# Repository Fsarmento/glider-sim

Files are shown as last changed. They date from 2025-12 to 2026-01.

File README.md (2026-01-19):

# glider-sim

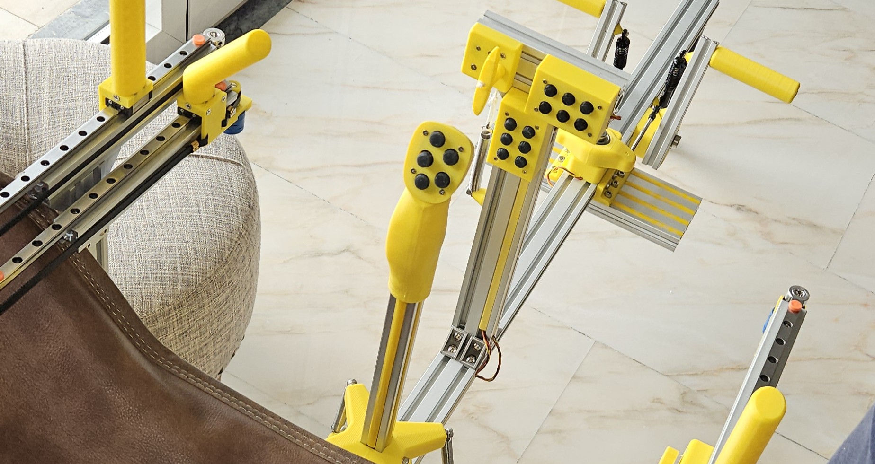
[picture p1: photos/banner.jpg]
Glider Sim


A glider flight simulation cockpit project. Includes 3D printable STL parts, bill of materials, and controller code.
This project was designed to be used with the **Condor 3** glider flight simulator.

---

If you enjoy this project and want to say thanks, you can **buy me a beer** via [GitHub Sponsors](https://github.com/sponsors/Fsarmento). 🍺

---

> [!NOTE]
> If you have any questions about this project, please use the [Discussions](https://github.com/Fsarmento/glider-sim/discussions) section. I'll try to answer them.

## Table of Contents

- [Introduction](#introduction)
- [Bill of Materials (BOM)](#bill-of-materials-bom)
  - [Frame](#frame)
  - [Joystick base](#joystick-base)
  - [Joystick controller](#joystick-controller)
  - [Rudder pedals](#rudder-pedals)
  - [Sliders](#sliders-up-to-3-sets-airbreaks-flaps-and-gear)
  - [Controller box](#controller-box)
  - [Trim lever](#trim-lever)
  - [Tow release](#tow-release)
  - [6-buttons box](#6-buttons-box-up-to-2-sets)
  - [Chair holder](#chair-holder)
  - [Wiring & connectors](#wiring--connectors)
- [Electronics overview](#electronics-overview)
  - [Main controller](#main-controller-glider_sim_main)
  - [Stick buttons controller](#stick-buttons-controller-glider_sim_stick_buttons)
  - [6-button box controller](#6button-box-controller-glider_sim_6_buttons)
- [Connections and Setup](#connections-and-setup)
- [Credits](#credits)
- [Photos](#photos)

---

## Introduction

This project uses aluminum profiles for the structure, 3D-printed parts, three PCBs to simplify electronic assembly, and accessories that can be easily purchased online from AliExpress or Banggood.
To assemble this cockpit, you will need a 3D printer and a soldering iron for electronics.

All 3D drawings are located in the `/stl` folder, organized into subfolders to make it easier to identify which module they belong to. I used PLA with 20% infill for all parts.

The links in the BOM list often point to sets, such as screw kits, where a single set contains the materials needed for multiple BOM lines.

For position sensing, the rudder pedals and joystick gimbal use linear Hall effect sensors (SS496A1), the sliders use 10-turn 10kΩ potentiometers, the trim lever uses a standard B10K potentiometer, and the tow release uses an end-switch commonly found in 3D printers.

The main controller uses an Arduino Pro Micro and is detected by the PC as a standard joystick. The stick buttons and each 6-button box use ESP32-C3 Supermini controllers. To simplify assembly without taking up much space, I designed 3 PCBs and provide the GERBER files in ZIP format in the `/PCB` folder. Nowadays, it is so easy and affordable to have PCBs manufactured that it makes sense to have boards custom-sized to your needs. To have the boards produced, simply go to the [JLCPCB](https://cart.jlcpcb.com/quote) website and upload the zip file. You do not need to change any of the default options on the site. With the cheapest shipping method, the production and shipping of each PCB costs around €7. In the case of the stick buttons, as space is very limited, I could only fit everything using SMD (surface-mount) buttons, which are harder to solder. For this reason, I suggest using the PCBA service to assemble the front of the PCB already with the buttons supplied by JLCPCB. To do this, at the bottom of the JLCPCB PCB configuration page, simply enable the "PCB Assembly" option and on the next page upload the BOM and CPL files provided inside the `/PCB` folder.

The code to upload to each controller is located inside the `/scripts` folder. You can use the Arduino IDE to upload the code to each controller.

I hope you enjoy assembling the cockpit and "flying" as much as I did!

> [!TIP]
> To understand how the Hall sensors work and how they should be installed, watch this video by Tim Station: [https://youtu.be/XcKmBWGFUn8?t=36&si=NRGCK4p2wdxqQ4Bu](https://youtu.be/XcKmBWGFUn8?t=36&si=NRGCK4p2wdxqQ4Bu)

## Bill of Materials (BOM)

> [!IMPORTANT]
> The AliExpress links do not have the correct product options pre-selected. Please make sure to select the correct options according to the item description.

### Frame

| Quantity | Type | Size | Length | Description | Shop |
|---|---|---|---|---|---|
| 1 | Aluminium Profile | 4040 | 900 | main frame | |
| 1 | Aluminium Profile | 4040 | 600 | side frame | |
| 3 | Aluminium Profile | 2040 | 300 | vertial arms | |
| 1 | Aluminium Profile | 2040 | 120 | front panel | |
| 3 | Aluminium Profile | 2020 | 200 | sliders | |
| 1 | Aluminium Profile | 2020 | 300 | joystick | |
| 2 | Aluminium Profile | 2020 | 150 | pedals | |
| 1 | Aluminium Profile | 2080 | 300 | feet rest | |
| 14 | Profile T connectors | 2020 |  | Profile Connector Corner Bracket set | [Link](https://s.click.aliexpress.com/e/_c4St6Xq9) |
| 2 | Profile 90 deg connector | 2020-2 L40 |  | L connector 2020-2 L40 (sliders base) | [Link](https://s.click.aliexpress.com/e/_c4KEbXQH) |
| 4 | Profile 90 deg connector | 2020-2 L20 |  | L connector 2020-2 L20 (sliders base) | [Link](https://s.click.aliexpress.com/e/_c4KEbXQH) |
| 1 | Profile 90 deg connector | 2040B-6 |  | L connector 2040B-6 (secondary slider) | [Link](https://s.click.aliexpress.com/e/_c4KEbXQH) |
| 3 | Telescopic Feet |  | 16.5CM-28.5CM | Telescopic Feet 16.5CM-28.5CM | [Link](https://s.click.aliexpress.com/e/_c4MEUecl) |
| 1 | Profile Slot Cover | 6mm (20 series) |  | Plastic Profile Slot Cover 20 Series | [Link](https://s.click.aliexpress.com/e/_c3PiaaX3) |

### Joystick base

| Quantity | Type | Size | Length | Description | Shop |
|---|---|---|---|---|---|
| 4 | Bearings | 10x26x8mm |  | Bearings 10x26x8mm (Inside diameter x Outside diameter x Width) | [Link](https://www.aliexpress.com/item/1005007668446060.html) |
| 2 | Shoulder Bolts | D10M8 | 20 | M8x20 Shoulder Bolts (10mm shoulder, 8mm thread) | [Link](https://s.click.aliexpress.com/e/_c3ETZkxx) |
| 2 | Shoulder Bolts | D10M8 | 10 | M8x10 Shoulder Bolts (10mm shoulder, 8mm thread) | [Link](https://s.click.aliexpress.com/e/_c3ETZkxx) |
| 8 | Bolts (Option A) | M5 | 10 | M5x10 Bolts DIN912 to fix springs | [Link](https://s.click.aliexpress.com/e/_c3y9Zvm3) |
| 5 | Bolts | M5 | 14 | M5x14 Bolts DIN912 | [Link](https://s.click.aliexpress.com/e/_c3y9Zvm3) |
| 10 | Bolts | M5 | 20 | M5x20 Bolts DIN912 | [Link](https://s.click.aliexpress.com/e/_c3y9Zvm3) |
| 15 | T-slot Nuts | M5 |  | M5 T-slot Nuts | [Link](https://s.click.aliexpress.com/e/_c3ZBusUH) |
| 2 | Magnets | 8x8x8 |  | 8mm cube magnets | [Link](https://s.click.aliexpress.com/e/_c4EhHqoz) |
| 2 | Hall Effect Sensor |  |  | Hall Effect Sensor SS496A1 | [Link](https://s.click.aliexpress.com/e/_c4PvMVrB) |
| 4 | Option A: Springs |  | 75 | 75x10x1.25mm Springs (Length x Outside Diameter x Wire Diameter) | [Link](https://s.click.aliexpress.com/e/_c2zo177f) |
| 4 | Option B: Oil shock absorber |  | 110 | oil shock absorber 110mm | [Link](https://s.click.aliexpress.com/e/_c3EF2605) |
| 4 | Option B: M3-M5 Adapter | M3-M5 | 10 | M3-M5  10mm Thread Adapter Screw Nuts | [Link](https://pt.aliexpress.com/item/1005007436046737.html) |

### Joystick controller

| Quantity | Type | Size | Length | Description | Shop |
|---|---|---|---|---|---|
| 4 | M2-M4 Adapter | M2-M4 | 8 | M2-M4  8mm Thread Adapter Screw Nuts | [Link](https://pt.aliexpress.com/item/1005007436046737.html) |
| 4 | Flat Bolts | M2 | 10 | M2x10 Flat Countersunk Head Bolt  | [Link](https://s.click.aliexpress.com/e/_c368gRLJ) |
| 1 | Controller ESP32-C3 |  |  | ESP32-C3 Supermini | [Link](https://s.click.aliexpress.com/e/_c2RvZ7EN) |
| 1 | Liquid Rubber |  |  | Silicon Liquid Rubber (buttons) | [Link](https://s.click.aliexpress.com/e/_c4Xd5cIh) |
| 1 | Black Pigment |  |  | Solid Color Black Pigment (buttons color) | [Link](https://pt.aliexpress.com/item/1005005830256537.html) |
| 1 | Option A: PCB stick-buttons |  |  | PCB stick-buttons | |
| 1 | Option A: Connector |  |  | JST-XH 2.54 connectors | [Link](https://s.click.aliexpress.com/e/_c3qvb13l) |
| 4 | Option B: Push Button Switch | 6x6x4.1 |  | (If  using 3D printed part instead of PCB) Push Button Switch  4x4x4.1 DIP (4x4x4.3 is also ok) | [Link](https://s.click.aliexpress.com/e/_c4dK0HMX) |
| 1 | Option B: 5-way Switch | 10x10x10 |  | (If  using 3D printed part instead of PCB) 5-way tactile switch 10x10x10 DIP | [Link](https://s.click.aliexpress.com/e/_c458W5dT) |

### Rudder pedals:

| Quantity | Type | Size | Length | Description | Shop |
|---|---|---|---|---|---|
| 3 | Shoulder Bolts | D10M8 | 30 | M8x30 Shoulder Bolts | [Link](https://s.click.aliexpress.com/e/_c3ETZkxx) |
| 6 | Bearings | 10x26x8mm |  | Bearings 10x26x8mm (Inside diameter x Outside diameter x Width) | [Link](https://www.aliexpress.com/item/1005007668446060.html) |
| 14 | Bolts | M5 | 10 | M5x10mm Bolts DIN912 (Feet Rest) | [Link](https://s.click.aliexpress.com/e/_c3y9Zvm3) |
| 4 | Bolts | M5 | 14 | M5x14mm Bolts DIN912 (Option A - Springs) | [Link](https://s.click.aliexpress.com/e/_c3y9Zvm3) |
| 16 | Bolts | M5 | 20 | M5x20mm Bolts DIN912 | [Link](https://s.click.aliexpress.com/e/_c3y9Zvm3) |
| 32 | T-slot Nuts | M5 |  | M5 T-slot Nuts | [Link](https://s.click.aliexpress.com/e/_c3ZBusUH) |
| 6 | T-slot Nuts | M3 |  | M3 T-slot Nuts | [Link](https://s.click.aliexpress.com/e/_c3ZBusUH) |
| 2 | Bolts | M5 | 100 | M5x100mm Bolts DIN912 | [Link](https://s.click.aliexpress.com/e/_c3y9Zvm3) |
| 2 | Link Rods | M3 | 110 | Stainless steel link rods with rod ends 110mm | [Link](https://s.click.aliexpress.com/e/_c3kGKZzb) |
| 2 | M3-M5 Adapter | M3-M5 | 10 | M3-M5  10mm Thread Adapter Screw Nuts (Link rod) | [Link](https://pt.aliexpress.com/item/1005007436046737.html) |
| 6 | Bolts | M3 | 20 | M3x18mm Bolts (link spacer/shock absorber) | [Link](https://s.click.aliexpress.com/e/_c3PQiYDP) |
| 2 | Bolts | M3 | 16 | M3x16mm Bolts (Shock absorber) | [Link](https://s.click.aliexpress.com/e/_c3PQiYDP) |
| 2 | Magnets | 8x8x8 |  | 8mm cube magnets | [Link](https://s.click.aliexpress.com/e/_c4EhHqoz) |
| 1 | Hall Effect Sensor |  |  | Hall Effect Sensor SS496A1 | [Link](https://s.click.aliexpress.com/e/_c4PvMVrB) |
| 2 | Option A: Springs |  | 75 | 75x10x1.25mm Springs (Length x Outside Diameter x Wire Diameter) | [Link](https://s.click.aliexpress.com/e/_c2zo177f) |
| 2 | Option B: Oil shock absorber |  | 110 | oil shock absorber 110mm | [Link](https://s.click.aliexpress.com/e/_c3B7cY09) |

### Sliders (up to 3 sets: airbreaks, flaps and gear)

| Quantity | Type | Size | Length | Description | Shop |
|---|---|---|---|---|---|
| 1 | Linear Guide Rail | MGN9C | 300 | Linear Guide Rail MGN9C, 300mm | [Link](https://s.click.aliexpress.com/e/_c4Eh7oYL) |
| 1 | Potentiometer | 10k Ohm |  | 10‑turn rotary potentiometer 10k Ohm | [Link](https://s.click.aliexpress.com/e/_c3l51dZt) |
| 1 | GT2 Idler | 20T W6 B5 |  | GT2  Idler 20 Tooth Width 6mm Bore 5mm | [Link](https://pt.aliexpress.com/item/1005003291106065.html) |
| 1 | GT2 belt | 6mm | 2m | GT2-6mm belt 2m (1 for 3 sets) | [Link](https://s.click.aliexpress.com/e/_c3UojoNn) |
| 2 | GT2 Belt Clamp | 6mm |  | GT2 Belt Clamp | [Link](https://s.click.aliexpress.com/e/_c39U7WKh) |
| 2 | Bolts | M5 | 8 | M5x8mm Bolts DIN912 (potentiometer arm) | [Link](https://s.click.aliexpress.com/e/_c3y9Zvm3) |
| 2 | Flat Bolts | M3 | 8 | M3x8 Flat Countersunk Head Bolt  (fix linear guided rail to 2020 profile) | [Link](https://s.click.aliexpress.com/e/_c368gRLJ) |
| 1 | Bolts | M3 | 16 | M3x16  Bolt  (fix GT2 Idler with Pulley Spacer) | [Link](https://s.click.aliexpress.com/e/_c368gRLJ) |
| 2 | Heat Insert Nut | M3 | 5 | Heat Insert Nut M3x5x4 (Inside diameter x length x outside diameter) for handle | [Link](https://s.click.aliexpress.com/e/_c4eRekuz) |
| 2 | Heat Insert Nut | M3 | 4 | Heat Insert Nut M3x4x4 (Inside diameter x length x outside diameter) for handle base | [Link](https://s.click.aliexpress.com/e/_c4eRekuz) |
| 4 | Flat Bolts | M3 | 12 | M3x12 Flat Countersunk Head Bolt  (fix base to linear guided rail carriage) | [Link](https://s.click.aliexpress.com/e/_c368gRLJ) |
| 4 | Flat Bolts | M3 | 8 | M3x8 Flat Countersunk Head Bolt  (fix handle & rubber belt link to base) | [Link](https://s.click.aliexpress.com/e/_c368gRLJ) |
| 2 | T-slot Nuts | M5 |  | M5 T-slot Nuts | [Link](https://s.click.aliexpress.com/e/_c3ZBusUH) |
| 3 | T-slot Nuts | M3 |  | M3 T-slot Nuts | [Link](https://s.click.aliexpress.com/e/_c3ZBusUH) |

### Controller box

| Quantity | Type | Size | Length | Description | Shop |
|---|---|---|---|---|---|
| 1 | Arduino pro micro |  |  | Arduino Pro Micro ATmega32U4 5V/16MHz | [Link](https://s.click.aliexpress.com/e/_c3PIP7hh) |
| 3 | pin headers |  |  | 2.54mm pin headers 3x 1x12 | [Link](https://s.click.aliexpress.com/e/_c3GXfIir) |
| 2 | Flat Bolts | M3 | 8 | M3x8 Flat Countersunk Head Bolt  (fix base to profile) | [Link](https://s.click.aliexpress.com/e/_c368gRLJ) |
| 2 | T-slot Nuts | M3 |  | M3 T-slot Nuts | [Link](https://s.click.aliexpress.com/e/_c3ZBusUH) |
| 3 | Heat Insert Nut | M2 | 3 | Heat Insert Nut M2x3x3.5 (Inside diameter x length x outside diameter) | [Link](https://s.click.aliexpress.com/e/_c4eRekuz) |
| 3 | Bolts | M2 | 5 | M2x5 Bolt | [Link](https://s.click.aliexpress.com/e/_c368gRLJ) |
| 1 | PCB glider-sim |  |  | PCB glider-sim | |

### Trim lever

| Quantity | Type | Size | Length | Description | Shop |
|---|---|---|---|---|---|
| 1 | Potentiometer |  |  | B10k Potentiometer | [Link](https://s.click.aliexpress.com/e/_c3d0xxqx) |
| 2 | Bolts | M5 | 10 | M5x10mm Bolts DIN912 | [Link](https://s.click.aliexpress.com/e/_c3y9Zvm3) |
| 2 | T-slot Nuts | M5 |  | M5 T-slot Nuts | [Link](https://s.click.aliexpress.com/e/_c3ZBusUH) |

### Tow release

| Quantity | Type | Size | Length | Description | Shop |
|---|---|---|---|---|---|
| 1 | End-switch |  |  | End-switch | [Link](https://s.click.aliexpress.com/e/_c3PR1Lm7) |
| 2 | Flat Bolts | M3 | 16 | M3x16 Flat Countersunk Head Bolt  (fix base to profile) | [Link](https://s.click.aliexpress.com/e/_c368gRLJ) |
| 2 | T-slot Nuts | M3 |  | M3 T-slot Nuts | [Link](https://s.click.aliexpress.com/e/_c3ZBusUH) |
| 2 | Flat Bolts | M2 | 10 | M2x10 Flat Countersunk Head Bolt  (fix end-switch) | [Link](https://s.click.aliexpress.com/e/_c368gRLJ) |
| 2 | Nut | M2 |  | M2 nut  (fix end-switch) | [Link](https://s.click.aliexpress.com/e/_c368gRLJ) |
| 2 | Washer | M2 |  | M2 washer  (fix end-switch) | [Link](https://s.click.aliexpress.com/e/_c368gRLJ) |
| 1 | Cord  | 1mm |  | 1mm cord  | [Link](https://s.click.aliexpress.com/e/_c3sErffN) |
| 1 | Spring |  | 75 | 75x10x1.25mm Springs (Length x Outside Diameter x Wire Diameter) | [Link](https://s.click.aliexpress.com/e/_c2zo177f) |
| 1 | Bolts | M5 | 14 | M5x14mm Bolts DIN912 (Spring) | [Link](https://s.click.aliexpress.com/e/_c3y9Zvm3) |
| 1 | T-slot Nuts | M5 |  | M5 T-slot Nuts | [Link](https://s.click.aliexpress.com/e/_c3ZBusUH) |

### 6-buttons box (up to 2 sets)

| Quantity | Type | Size | Length | Description | Shop |
|---|---|---|---|---|---|
| 4 | Heat Insert Nut | M2 | 4 | Heat Insert Nut M2x4x3.5 (Inside diameter x length x outside diameter) | [Link](https://s.click.aliexpress.com/e/_c4eRekuz) |
| 4 | Bolts | M2 | 5 | M2x5 Bolt | [Link](https://s.click.aliexpress.com/e/_c368gRLJ) |
| 2 | Bolts | M5 | 8 | M5x8 Bolt ISO7380 (use bolt from profile T connectors) | [Link](https://s.click.aliexpress.com/e/_c3y9Zvm3) |
| 2 | T-slot Nuts | M5 |  | M5 T-slot Nuts | [Link](https://s.click.aliexpress.com/e/_c3ZBusUH) |
| 1 | Controller ESP32-C3 |  |  | ESP32-C3 Supermini | [Link](https://s.click.aliexpress.com/e/_c2RvZ7EN) |
| 6 | Push Button Switch | 6x6x4.1 |  | Push Button Switch  4x4x4.1 DIP (4x4x4.3 is also ok) | [Link](https://s.click.aliexpress.com/e/_c4dK0HMX) |
| 1 | Option A: Connector |  |  | 2.54mm pin header L 1x3 | [Link](https://s.click.aliexpress.com/e/_c3WdSsM7) |
| 1 | Option B: Connector |  |  | JST-XH 2.54 connectors | [Link](https://s.click.aliexpress.com/e/_c3qvb13l) |
| 1 | Liquid Rubber |  |  | Silicon Liquid Rubber (buttons) | [Link](https://s.click.aliexpress.com/e/_c4Xd5cIh) |
| 1 | Black Pigment |  |  | Solid Color Black Pigment (buttons color) | [Link](https://pt.aliexpress.com/item/1005005830256537.html) |
| 1 | PCB 6-button-box |  |  | PCB 6-button-box | |

### Chair holder

| Quantity | Type | Size | Length | Description | Shop |
|---|---|---|---|---|---|
| 2 | Crab Clamp |  |  | Crab Clamp with 3/8" hole | [Link](https://s.click.aliexpress.com/e/_c2xOmsnF) |
| 2 | Bolts | 3/8" | 2" | UNC hex socket cap screw 3/8-16 Length: 2" | [Link](https://s.click.aliexpress.com/e/_c3Cszrbf) |
| 8 | Bolts | M5 | 14 | M5x14 Bolts | [Link](https://s.click.aliexpress.com/e/_c3y9Zvm3) |
| 8 | T-slot Nuts | M5 |  | M5 T-slot Nuts | [Link](https://s.click.aliexpress.com/e/_c3ZBusUH) |

### Wiring & connectors

| Quantity | Type | Size | Length | Description | Shop |
|---|---|---|---|---|---|
| 2 | Cables | 26AWG | 10m | 26AWG servo extension cable 10m | [Link](https://s.click.aliexpress.com/e/_c3AXPQ6B) |
| 12 | Connectors |  |  | servo JR Male connectors (set of 20) | [Link](https://s.click.aliexpress.com/e/_c2uRVjab) |

## Electronics overview

This project includes three **electronic** modules: the main controller, the stick buttons controller, and the 6‑button box controller.

---

### Main controller (Glider_sim_main)

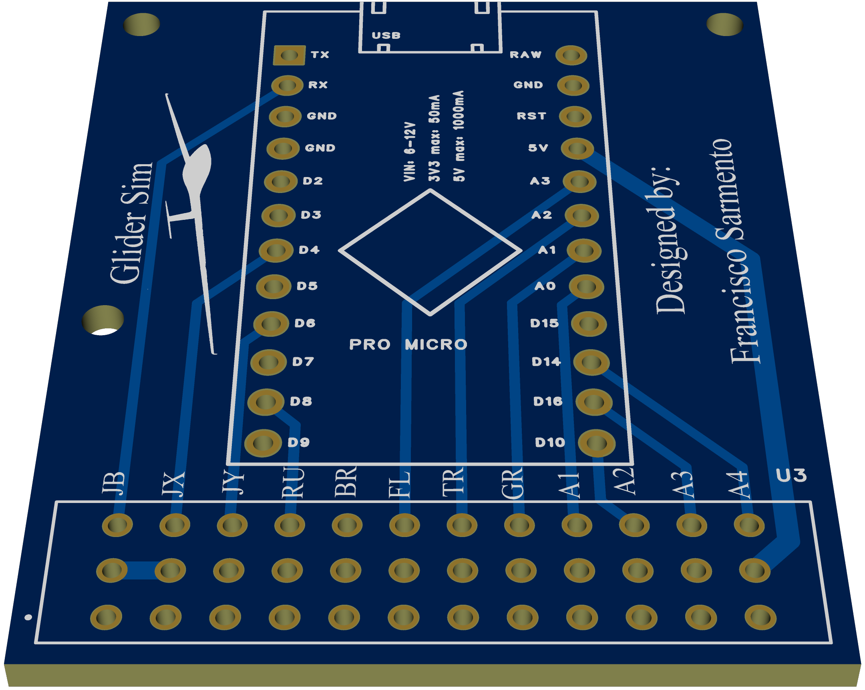
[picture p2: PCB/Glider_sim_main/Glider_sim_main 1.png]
Glider_sim_main


The main controller collects all joystick axes, sliders, pedals, buttons and external box inputs and exposes them to the PC as a USB HID joystick.
It is built around an Arduino Pro Micro based on the ATmega32U4 running at 5 V / 16 MHz, which integrates native USB support and simplifies the joystick firmware implementation.

All external signals (potentiometers, Hall sensors, end‑switches and button matrices) connect to this board through pin headers and JST/servo‑style connectors to ease wiring and maintenance.
The PCB can be ordered from [JLCPCB](https://cart.jlcpcb.com/quote) using the provided GERBER files for approximately 7 €, and all components are intended to be assembled manually by soldering through‑hole and basic SMD parts.

---

### Stick buttons controller (Glider_sim_stick_buttons)

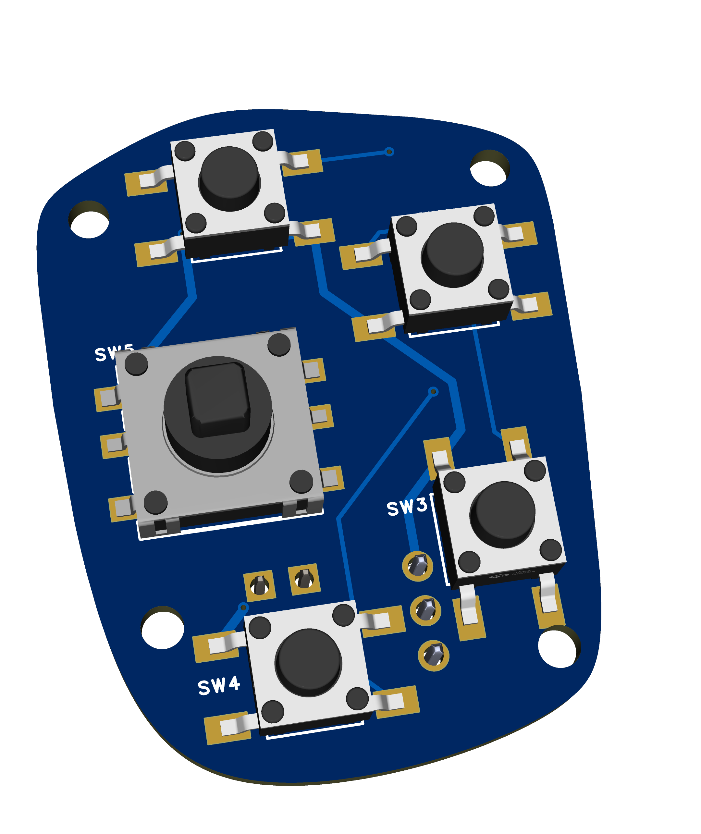
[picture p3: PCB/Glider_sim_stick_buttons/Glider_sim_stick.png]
Glider_sim_stick_buttons


The stick head contains one 5‑way joystick‑type tactile switch plus four front push buttons, with an optional fifth rear push button for additional functions such as push‑to‑talk or wheel brake.
Due to limited space inside the handle, these buttons are read by a dedicated ESP32‑C3 Supermini module, which communicates with the main controller over a one‑way UART link.

The ESP32‑C3 Supermini runs internally at 3.3 V logic level but can be powered from a 5 V supply, and its TX output is directly connected to the Arduino Pro Micro RX input because 3.3 V is high enough to be detected as a logic HIGH by the 5 V ATmega32U4.
This architecture reduces the number of wires going through the moving stick, since only power, ground and a single serial data line are required between the handle and the main controller.

Two assembly options are provided for the stick electronics.
In the PCB‑based version, a small custom PCB holds the 5‑way switch and four push buttons; this PCB can be manufactured and partially assembled at [JLCPCB](https://cart.jlcpcb.com/quote), including the tactile switches, for a cost around 30 €.

In the no‑PCB version, the 3D printed part `buttons-support-no-pcb.stl` mechanically supports all five buttons, and the ESP32‑C3 Supermini is wired point‑to‑point to each switch using flexible hookup wire and then fixed inside the handle with hot glue.
This option is cheaper but requires more careful manual soldering and routing because of the tight internal space.

---

### 6‑button box controller (Glider_sim_6_buttons)

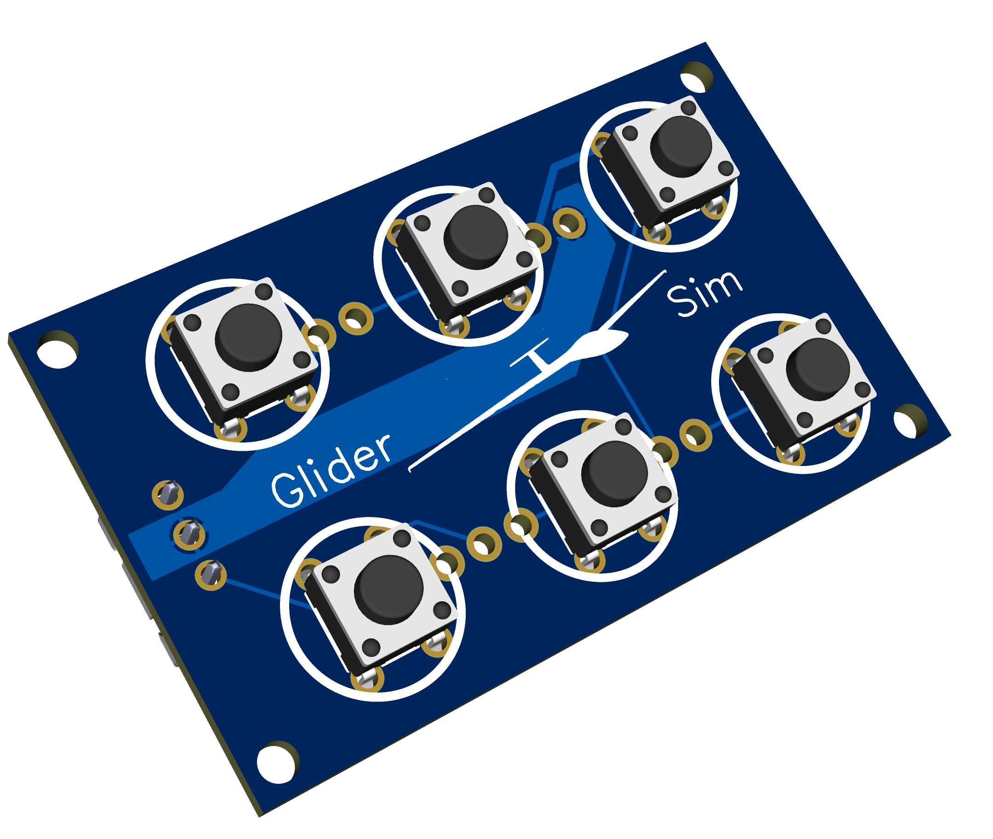
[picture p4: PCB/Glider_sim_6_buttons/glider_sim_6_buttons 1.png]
Glider_sim_6_buttons


The 6‑button box provides six generic push buttons that can be mapped to any simulator function, for example views, trim presets or radio shortcuts.
This module is built around an ESP32‑C3 Supermini, but in this case the communication with the main controller does not use the same serial protocol as the stick buttons.

Instead, the 6‑button box drives a single analog line going to the main controller.
Depending on which button is pressed, the circuit sets a different duty / analog value on this line (in the 0–255 range), and the Arduino Pro Micro interprets this value to identify which of the six buttons is active.

The PCB for this module can be manufactured at [JLCPCB](https://cart.jlcpcb.com/quote) using the provided GERBER files for around 7 €, and all components are intended to be soldered manually.
The enclosure is fully 3D printed and uses heat‑insert nuts and M2 screws to secure the PCB, making maintenance and button replacement straightforward.

## Connections and Setup

The main controller must be connected to all modules before performing calibration in Windows and configuration in Condor 3. The main board is connected to the PC via the USB port and is detected as a standard HID joystick.

- The joystick controller (ESP32‑C3 in the stick head) must be connected to the main board on connector **JB** (Joystick Buttons), using the **RX** pin on the main board to receive the UART signal from the ESP32‑C3.
- The joystick Hall sensors must be connected to the main controller on inputs **JX** (pin 4 / A6) and **JY** (pin 6 / A7), corresponding to the X and Y axes of the stick.
- The analog inputs such as sliders and the trim lever must be connected to **RU** (pin 8 / A8), **BR** (pin 9 / A9), **FL** (pin 21 / A3), **TR** (pin 20 / A2) and **GR** (pin 19 / A1).
- The auxiliary inputs **Aux1** (pin 18 / A0) and **Aux4** (pin 14) are **I/O** inputs configured as **INPUT_PULLUP**, suitable for switches like the tow release; the other terminal of the switch must be connected to **GND**.
- The auxiliary inputs **Aux2** (pin 10 / A10) and **Aux3** (pin 16) are **PWM** inputs where up to two ESP32‑C3 controllers from the 6‑button boxes can be connected.

After wiring everything, go to Windows **Game Controller Settings** and calibrate the joystick and sliders.

Command assignments to Condor 3 functions can be performed directly in the Condor 3 setup. Personally, I prefer to only assign the analog inputs (joystick, rudder, and sliders) directly in Condor 3 and use the **JoyToKey** software to map the joystick buttons to predefined keyboard input commands in Condor 3.

In Condor 3, the Gear command to raise and lower the landing gear is a single key press and cannot be assigned to a slider. To use the right slider to control the Gear, I configured it in JoyToKey as follows:
- Slider1(<0) -> G
- Slider1(>0) -> G

This way, moving the right slider from one end to the other is equivalent to pressing the G key, which raises or lowers the landing gear.

---

## Credits

The joystick handle design was adapted from the [OpenVario Remote Stick project](https://www.openvario.org/doku.php?id=projects:remote_00:top), created by the OpenVario community.

The joystick and rudder pedals were adapted from the [Flight-Simulator-Joystick](https://github.com/TomStanton/Flight-Simulator-Joystick) project, developed by Tim Station.

## Photos

### Front View
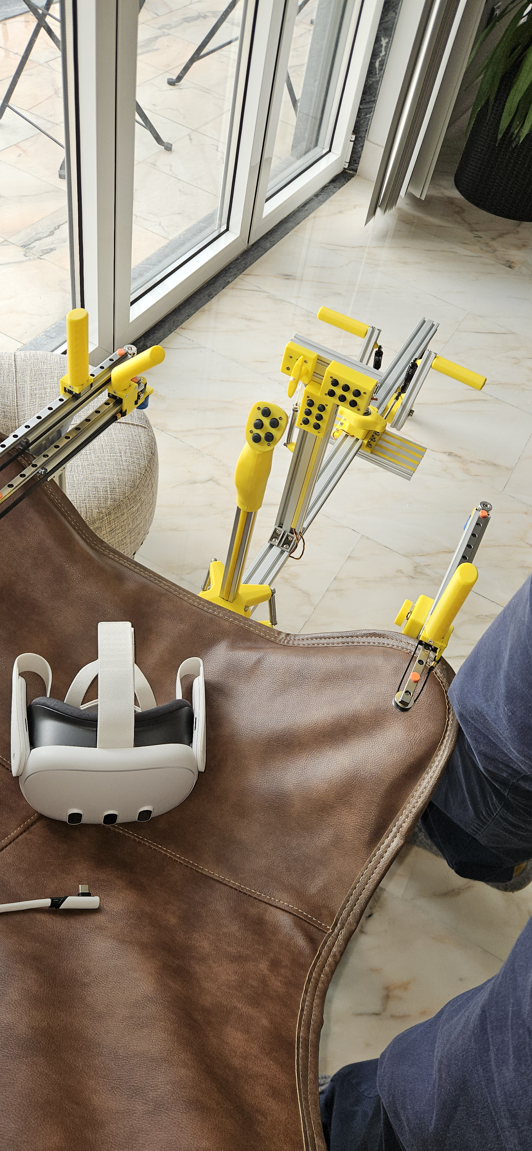
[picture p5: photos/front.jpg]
Front View


### Back View
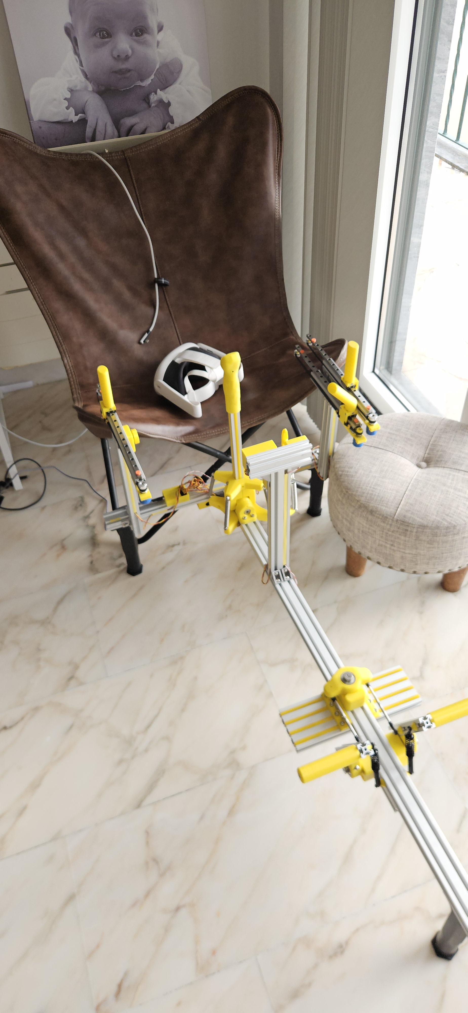
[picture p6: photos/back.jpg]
Back View


### Control Stick
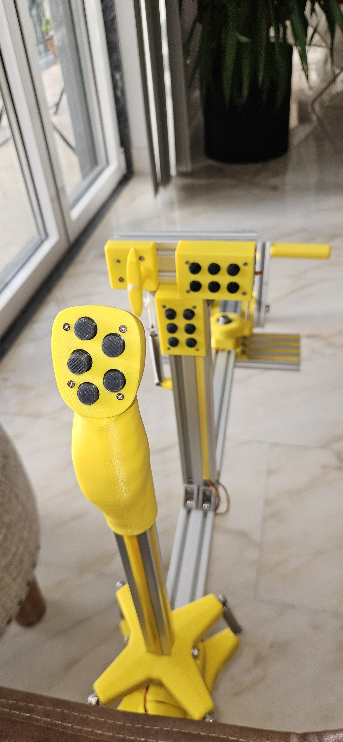
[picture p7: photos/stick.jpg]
Control Stick


### Rudder Pedals
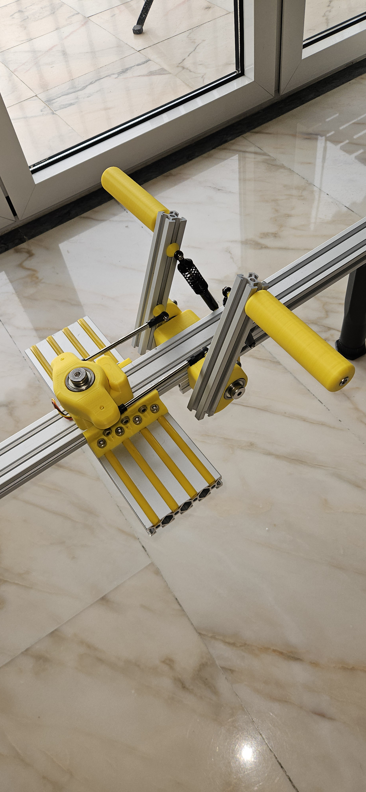
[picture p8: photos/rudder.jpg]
Rudder Pedals


### Flaps & Airbrakes
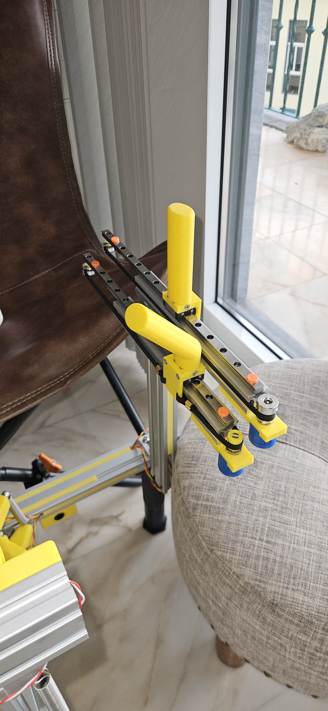
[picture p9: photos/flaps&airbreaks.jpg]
Flaps & Airbrakes


### Gear & Trim
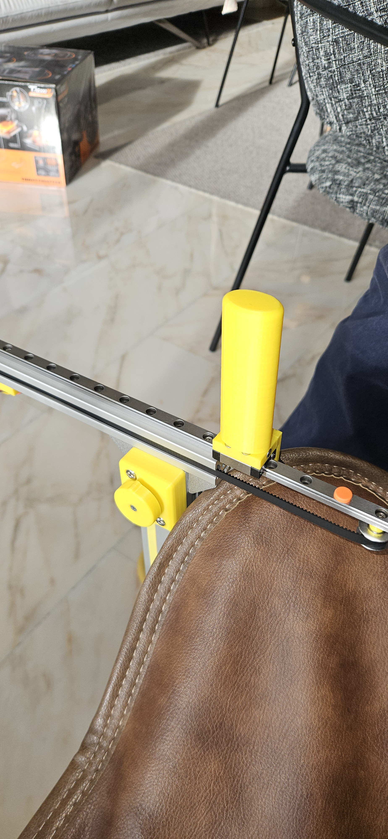
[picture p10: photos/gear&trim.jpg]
Gear & Trim


### PCBs Front

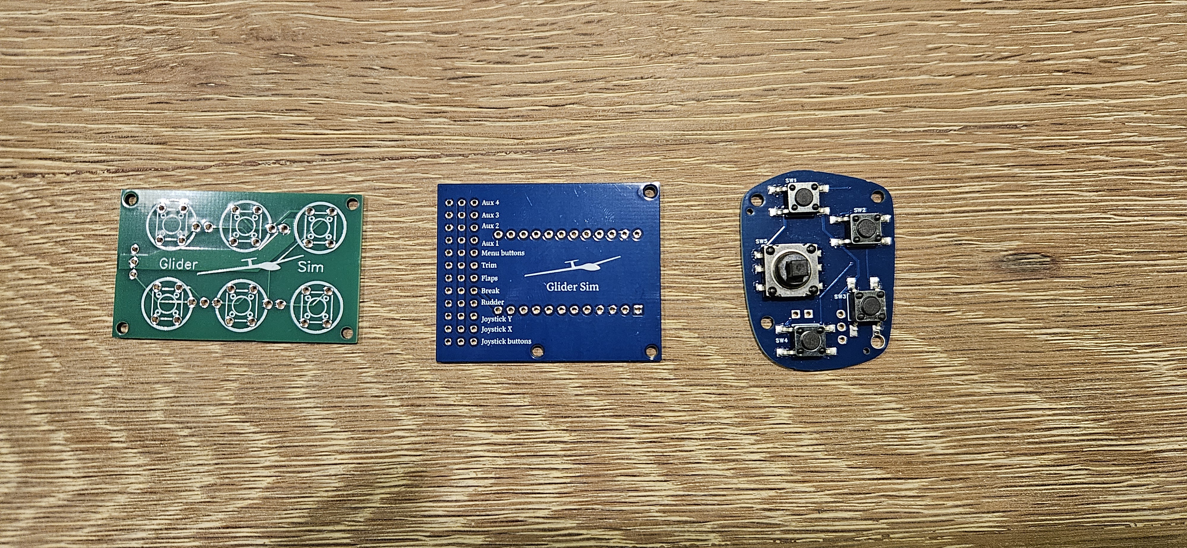
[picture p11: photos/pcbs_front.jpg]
PCBs Front


### PCBs Back

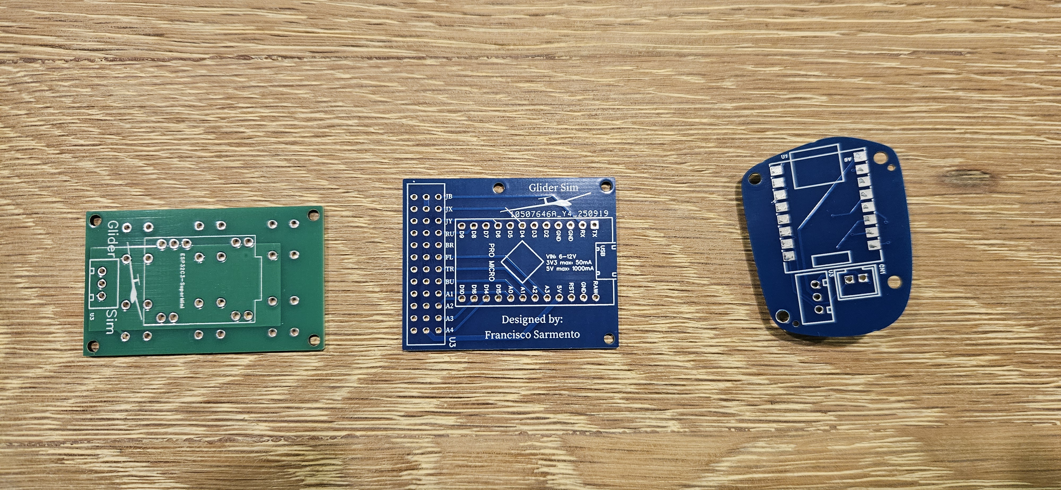
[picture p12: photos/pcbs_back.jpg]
PCBs Back


### Stick Buttons

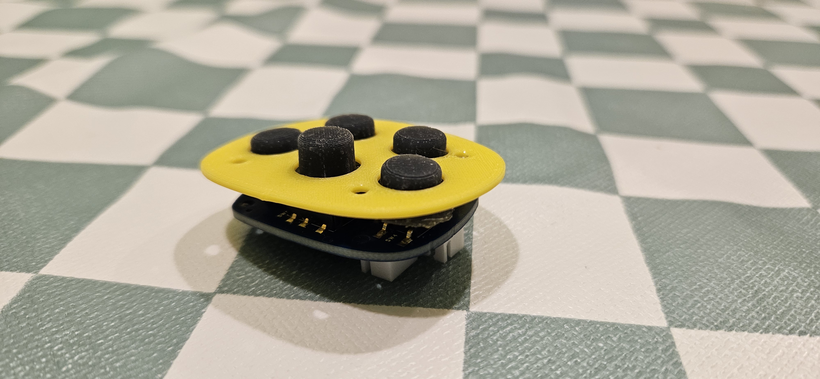
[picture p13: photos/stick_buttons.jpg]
Stick Buttons


### Stick Buttons Assembly

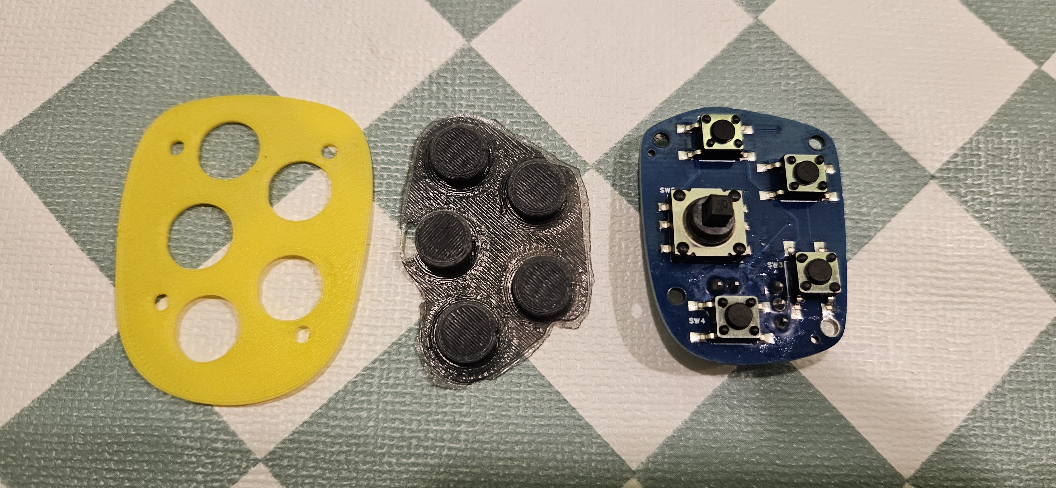
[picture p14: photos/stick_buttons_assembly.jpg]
Stick Buttons Assembly


### Stick Buttons Options

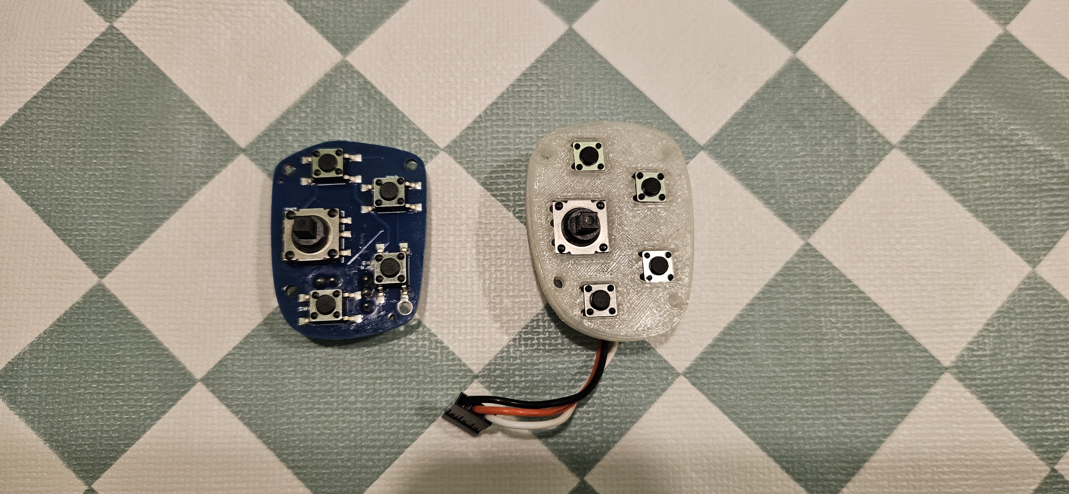
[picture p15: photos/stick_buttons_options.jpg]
Stick Buttons Options


### Stick Buttons Options (Back)

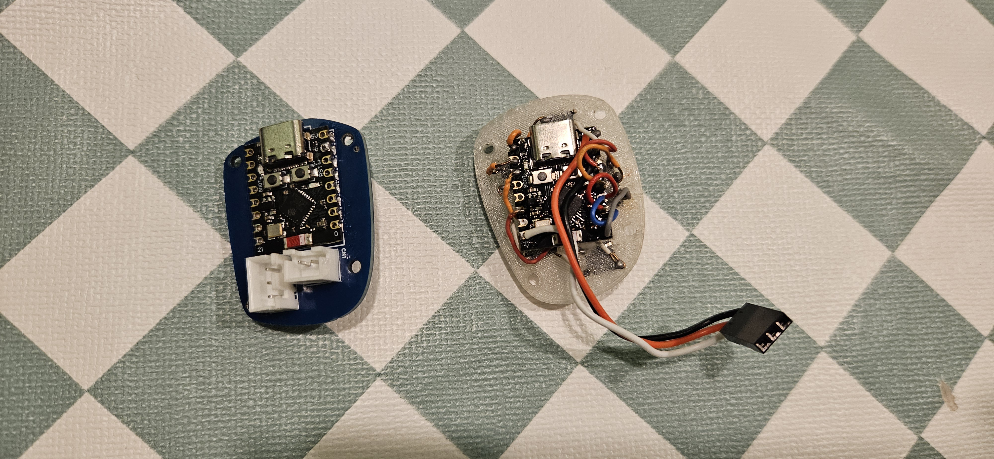
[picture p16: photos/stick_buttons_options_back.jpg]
Stick Buttons Options (Back)


### Stick Option STL

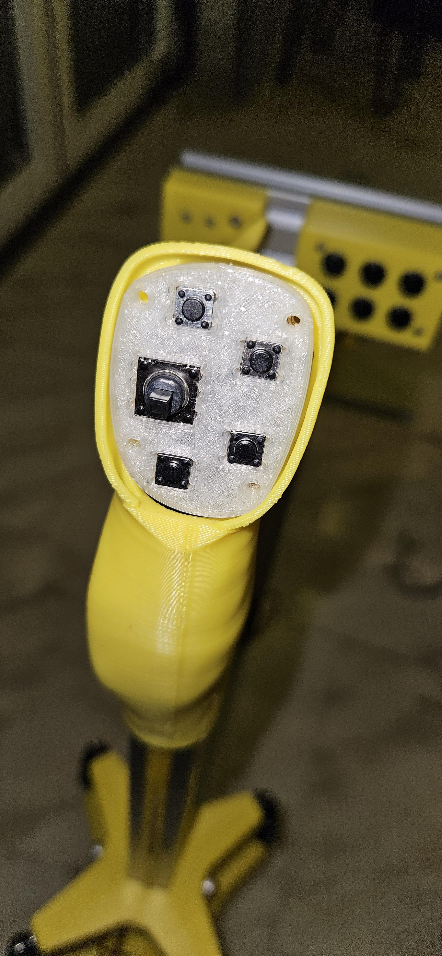
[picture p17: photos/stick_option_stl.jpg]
Stick Option STL


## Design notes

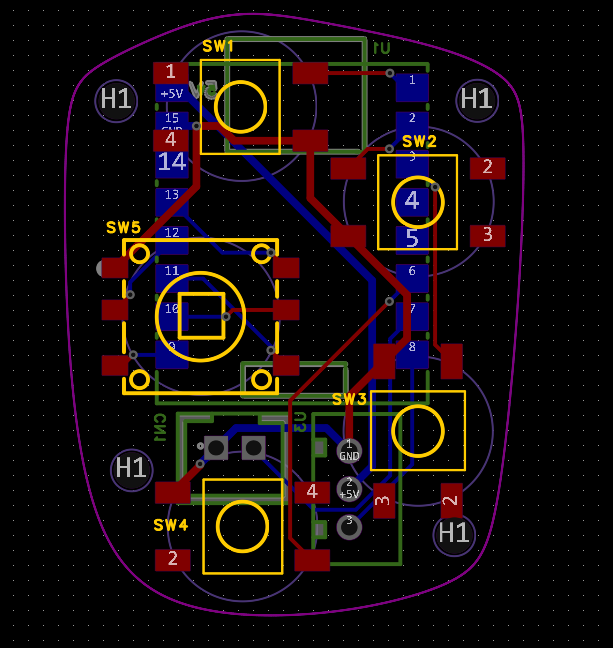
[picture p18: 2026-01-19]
PCB/Glider_sim_stick_buttons/PCB_stick_schematic.png

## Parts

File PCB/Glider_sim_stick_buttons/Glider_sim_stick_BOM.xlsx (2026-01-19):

No. | Quantity | Comment | Designator | Footprint | Value | Manufacturer Part | Manufacturer | Supplier Part | Supplier
1 | 1 | XH2.54-2PIN-直针 | CN1 | CONN-TH_XH2.54-2P |  | XH2.54-2PIN-直针 |  | C9900011425 | LCSC
2 | 4 | TSA063G43-250 | SW1,SW2,SW3,SW4 | KEY-SMD_4P-L6.0-W6.0-P4.50-LS10.0 |  | TSA063G43-250 | BRIGHT(博瑞泰) | C294564 | LCSC
3 | 1 | WS-1003-ARW10026 | SW5 | SW-SMD_6P-L10.2-W10.2_TSX103G86-250 |  | WS-1003-ARW10026 | XUNPU(讯普) | C42377835 | LCSC
4 | 1 | ESP32C3-SuperMini | U1 | COMM-SMD_16P-L22.5-W18.0-P2.54-TL |  | ESP32C3-SuperMini |  | C9900147397 | LCSC
5 | 1 | XH2.54_3PIN_立式 | U3 | CONN-TH_XH2.54_3PIN |  | XH2.54_3PIN_立式 |  | C9900001961 | LCSC

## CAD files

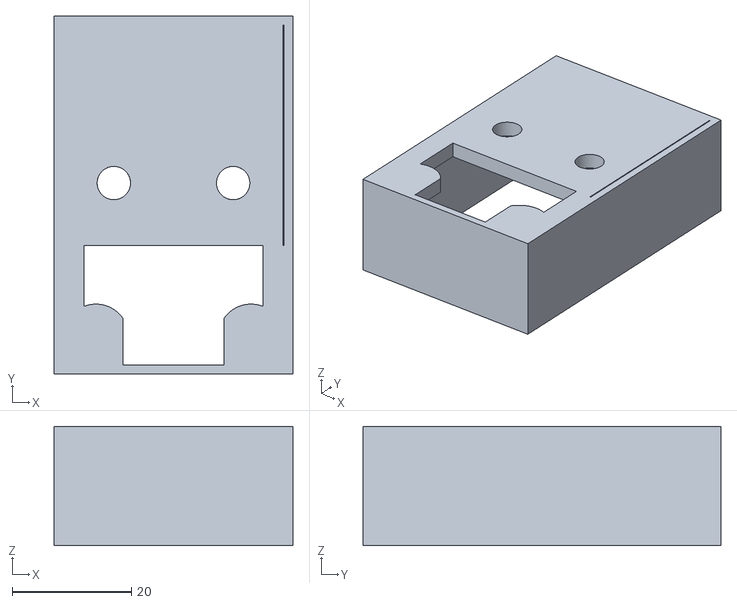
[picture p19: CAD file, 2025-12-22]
stl/6-buttons-box/6-buttons-box-main.stl
40.0 x 60.0 x 20.0

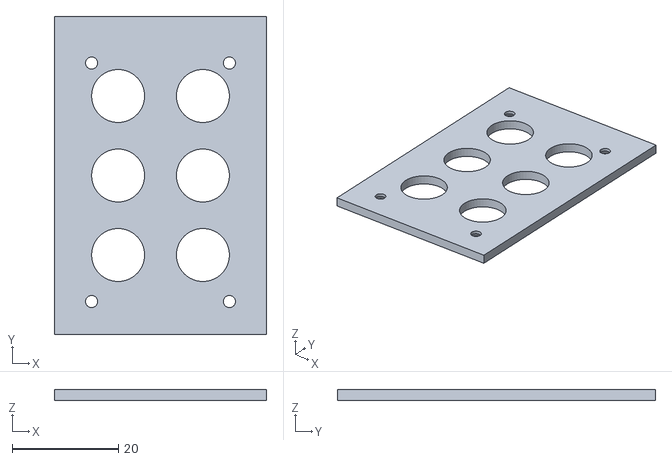
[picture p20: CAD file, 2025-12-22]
stl/6-buttons-box/6-buttons-box-cover.stl
40.0 x 60.0 x 2.00

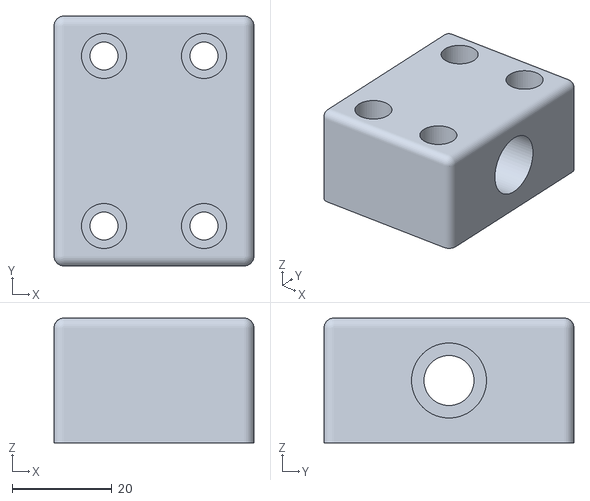
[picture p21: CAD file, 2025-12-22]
stl/chair-holder/chair-holder.stl
40.0 x 50.0 x 25.0

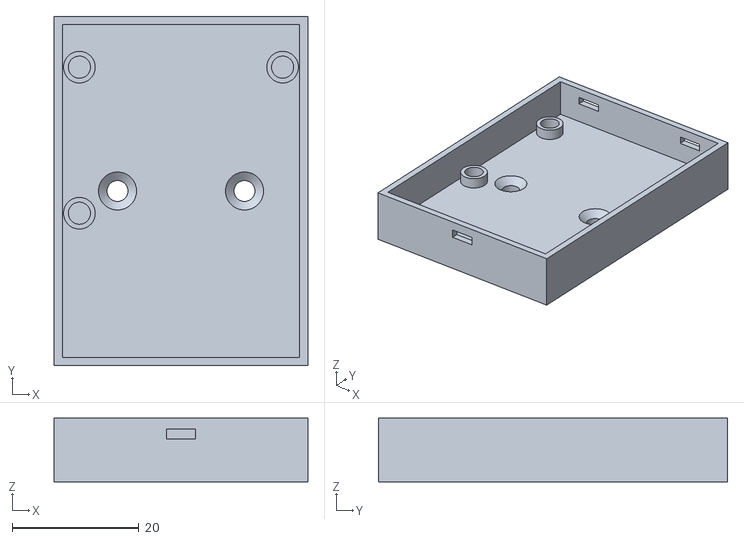
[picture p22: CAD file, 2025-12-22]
stl/controller-box/controller-box-bottom.stl
40.0 x 55.0 x 10.0

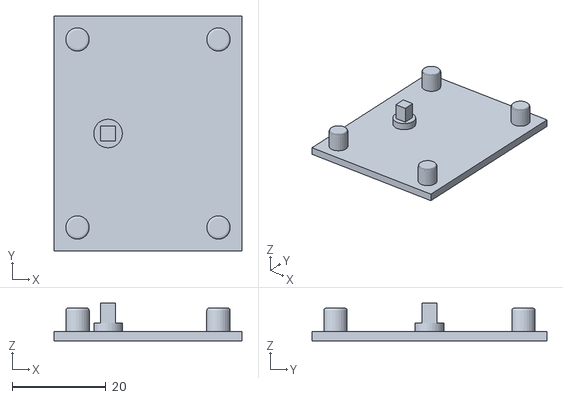
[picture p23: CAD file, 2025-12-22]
stl/joystick/buttons-mold/gummitasten-mold-unterseite.stl
40.0 x 50.0 x 8.05

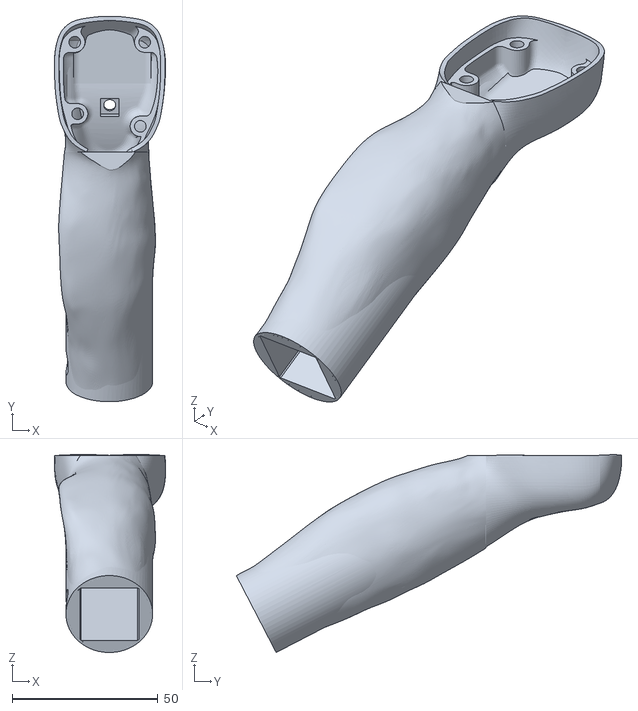
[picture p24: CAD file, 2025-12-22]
stl/joystick/stick-v32-fs.stl
38.2 x 132.4 x 68.0

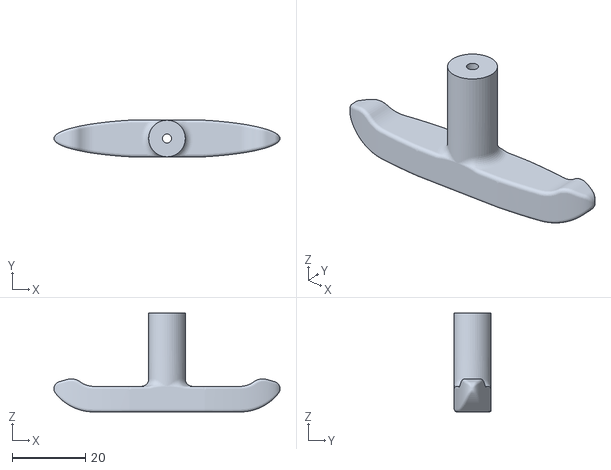
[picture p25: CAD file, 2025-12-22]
stl/release/release-handle.stl
61.7 x 10.0 x 27.0

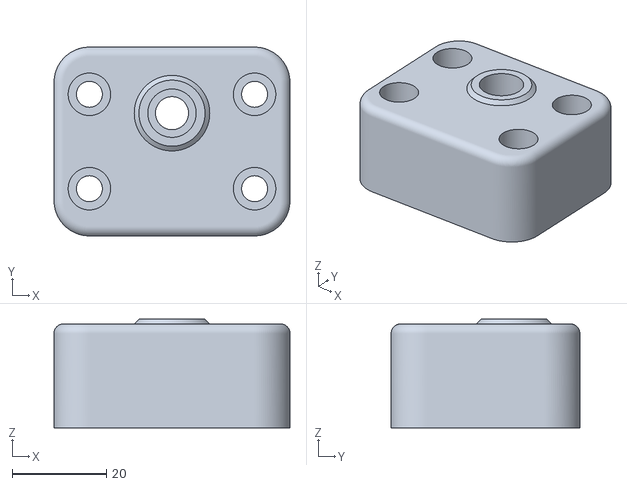
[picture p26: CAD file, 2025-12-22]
stl/rudder/pedal-mount-block.stl
50.0 x 40.0 x 23.0

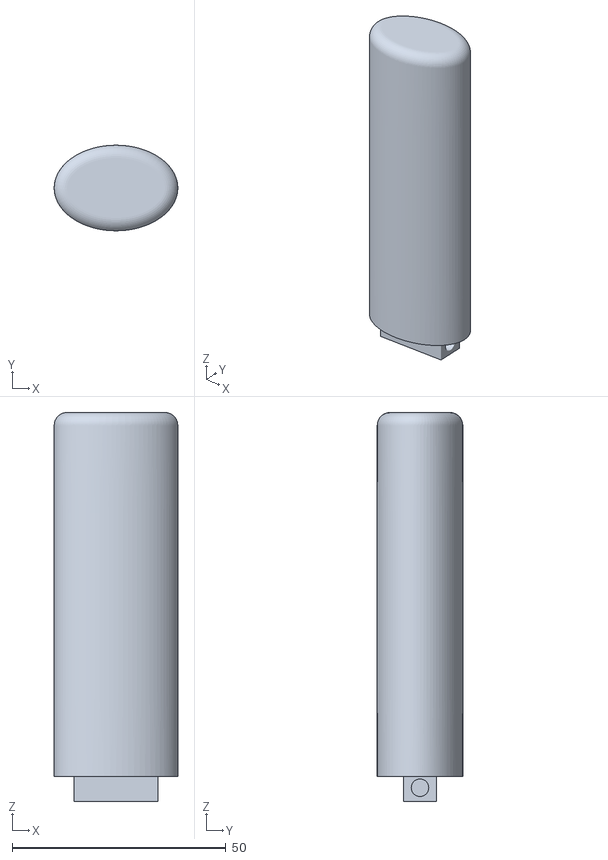
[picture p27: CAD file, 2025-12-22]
stl/sliders/handle-straight.stl
28.9 x 20.0 x 90.9

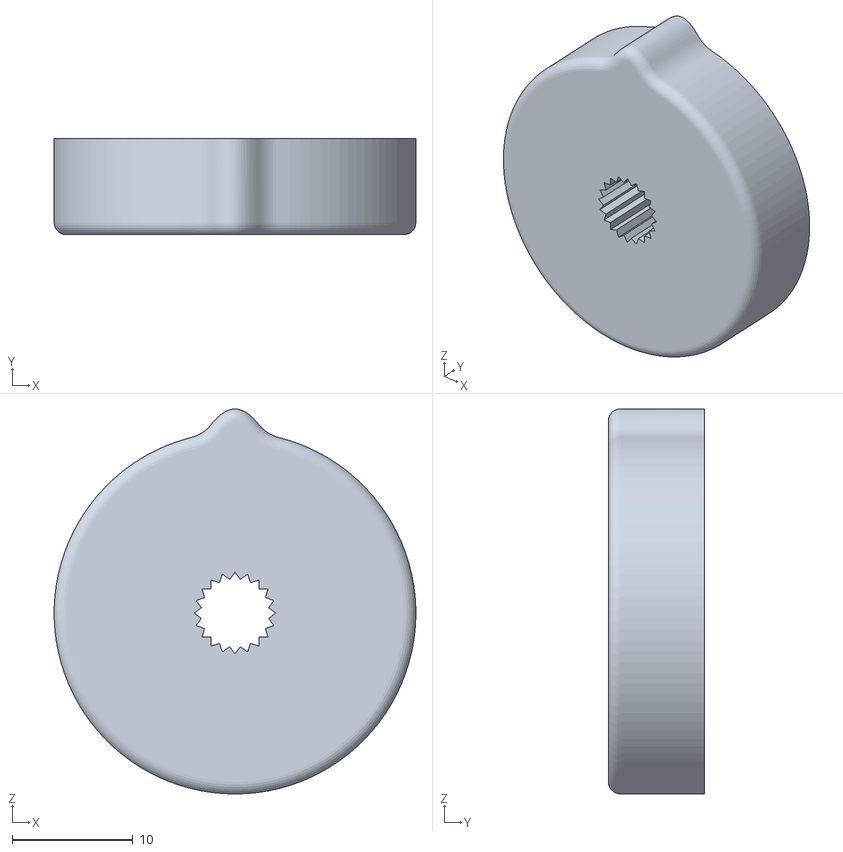
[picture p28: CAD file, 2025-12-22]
stl/trim/trim-wheel.stl
30.0 x 8.00 x 31.9

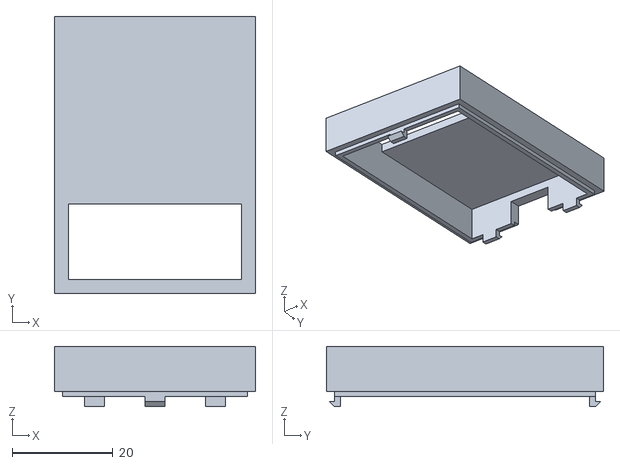
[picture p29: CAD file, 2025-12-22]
stl/controller-box/controller-box-top.stl
40.0 x 55.0 x 12.0

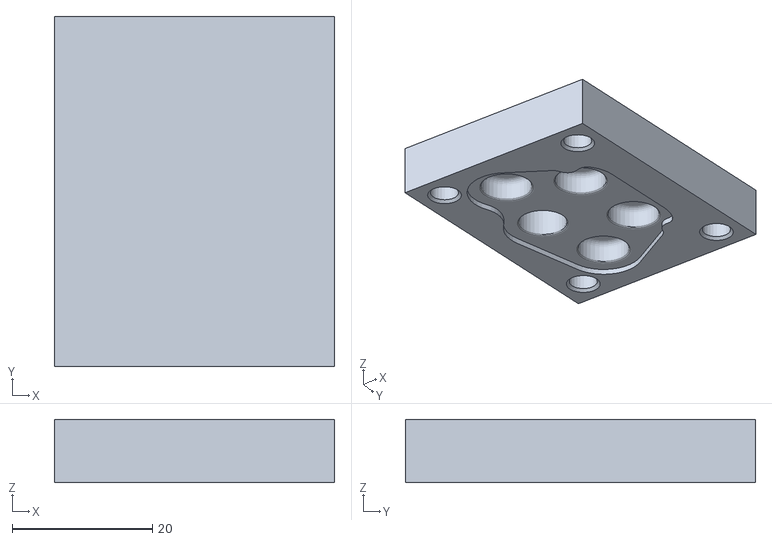
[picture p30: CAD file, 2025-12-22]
stl/joystick/buttons-mold/gummitasten-mold-oberseite.stl
40.0 x 50.0 x 9.05

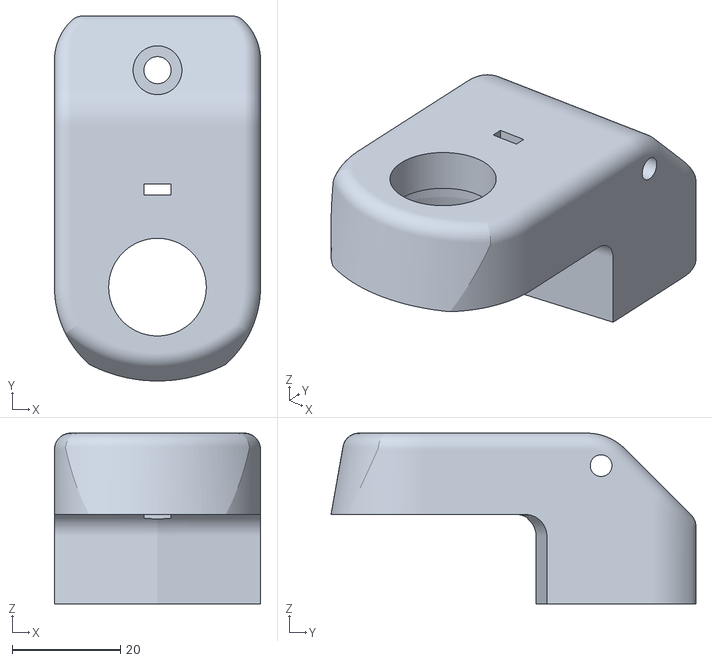
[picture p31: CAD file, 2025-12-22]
stl/joystick/joystick-gimbal-top.stl
38.0 x 67.3 x 31.5

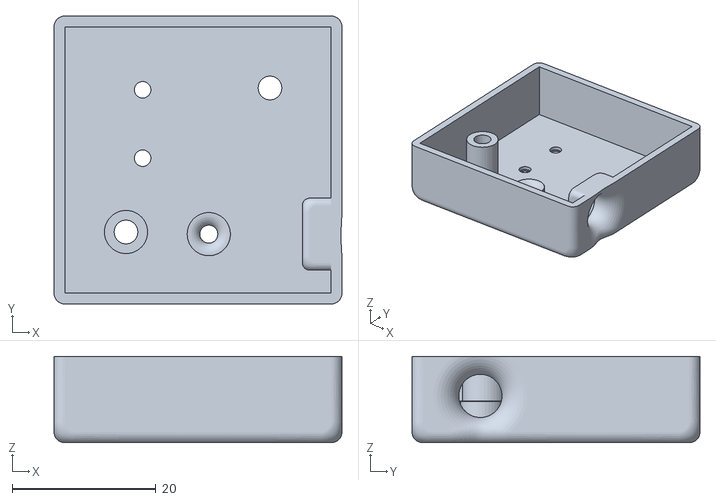
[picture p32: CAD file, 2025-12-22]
stl/release/release-box.stl
40.0 x 40.0 x 12.0

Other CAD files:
stl/rudder/pedal-pivot.stl
stl/sliders/spur-gear-potentiometer.stl
stl/trim/trim-box.stl
stl/joystick/joystick-spring-mount-bottom.stl
stl/joystick/buttons-support-no-pcb.stl
stl/joystick/joystick-gimbal-base.stl
stl/joystick/joystick-gimbal-middle.stl
stl/joystick/joystick-spring-mount-top.stl
stl/joystick/stick-front-plate.stl
stl/release/pedal-spring-spacer-m3.stl
stl/release/pedal-spring-spacer-m5.stl
stl/release/release-lever.stl
stl/rudder/feet-rest.stl
stl/rudder/pedal-spring-spacer-m3.stl
stl/rudder/pedal-spring-spacer-m5.stl
stl/rudder/rudder-linkage-mount-block.stl
stl/rudder/rudder-linkage-pivot.stl
stl/rudder/rudder-pedal.stl
stl/sliders/handle-angled.stl
stl/sliders/handle-base.stl
stl/sliders/potentiometer-arm.stl
stl/sliders/pulley-spacer.stl
stl/sliders/rubber-belt-link.stl

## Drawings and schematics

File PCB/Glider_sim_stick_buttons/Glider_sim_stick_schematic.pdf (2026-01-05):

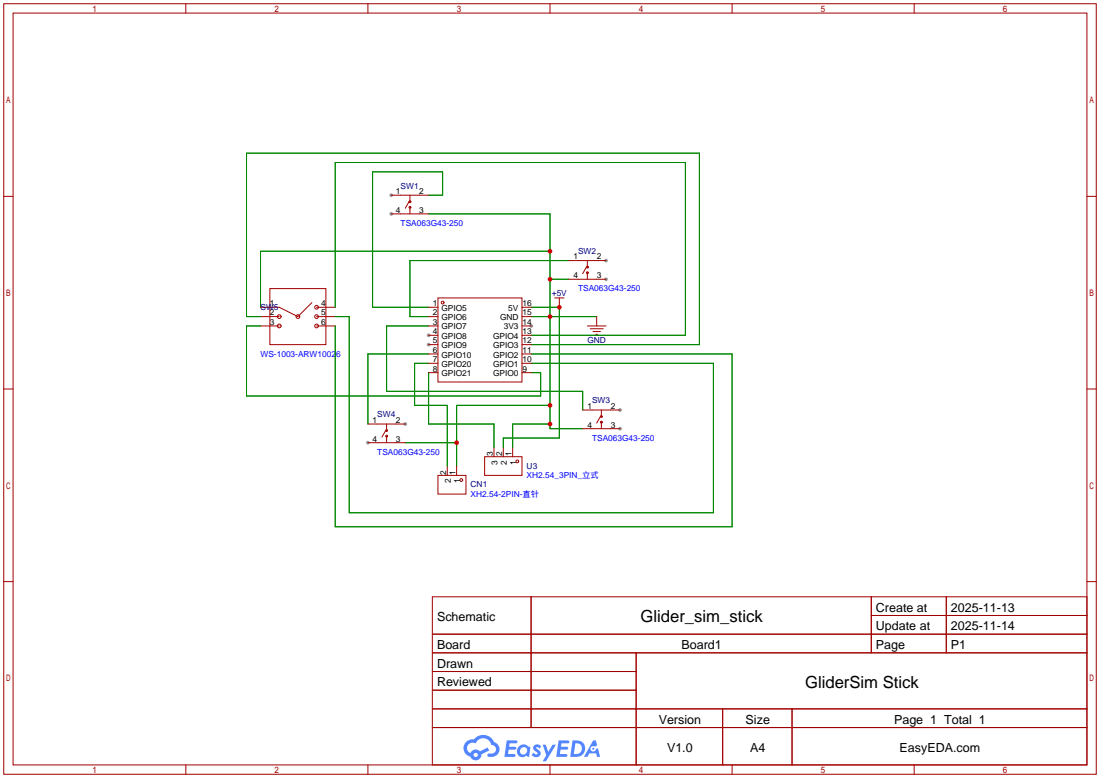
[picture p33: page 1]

Schematic | Glider_sim_stick | Create at | 2025-11-13

Update at | 2025-11-14

Board | Board1 | Page | P1
Drawn | | GliderSim Stick
Reviewed

Version | Size | Page 1 Total 1
V1.0 | A4 | EasyEDA.com

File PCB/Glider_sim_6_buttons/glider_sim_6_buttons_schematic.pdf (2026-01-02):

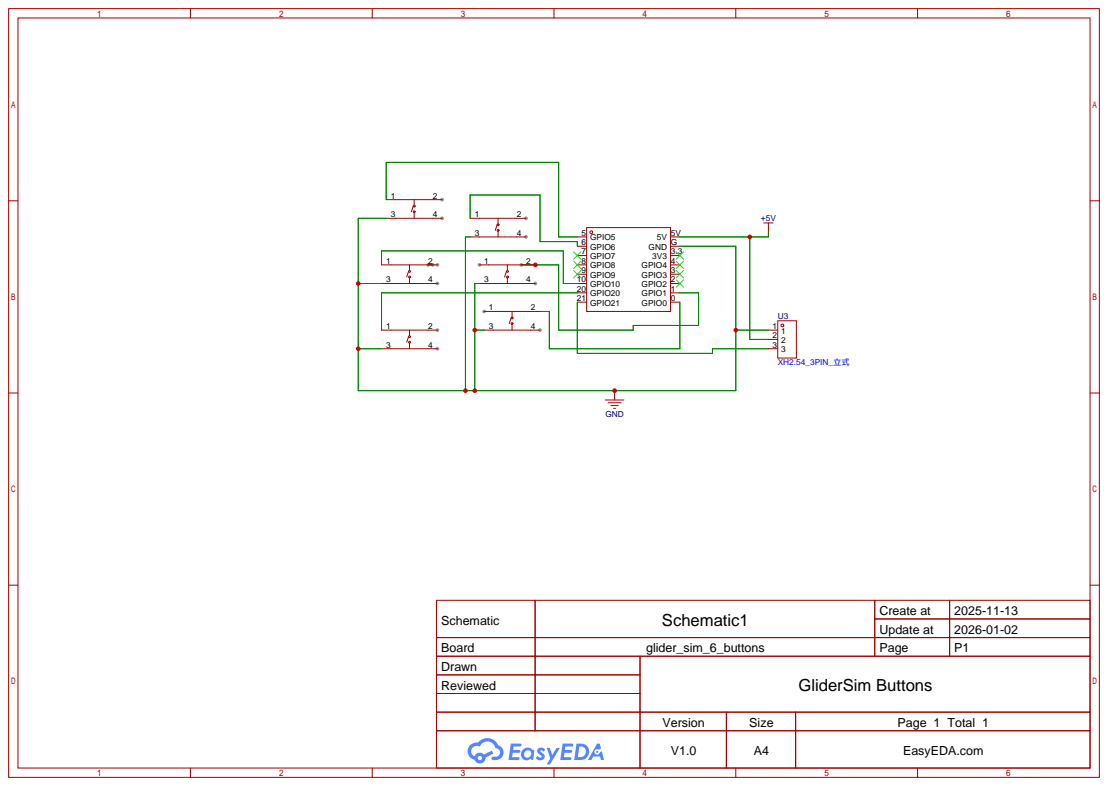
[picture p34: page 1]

Schematic | Schematic1 | Create at | 2025-11-13

Update at | 2026-01-02

Board | glider_sim_6_buttons | Page | P1
Drawn | | GliderSim Buttons
Reviewed

Version | Size | Page 1 Total 1
V1.0 | A4 | EasyEDA.com

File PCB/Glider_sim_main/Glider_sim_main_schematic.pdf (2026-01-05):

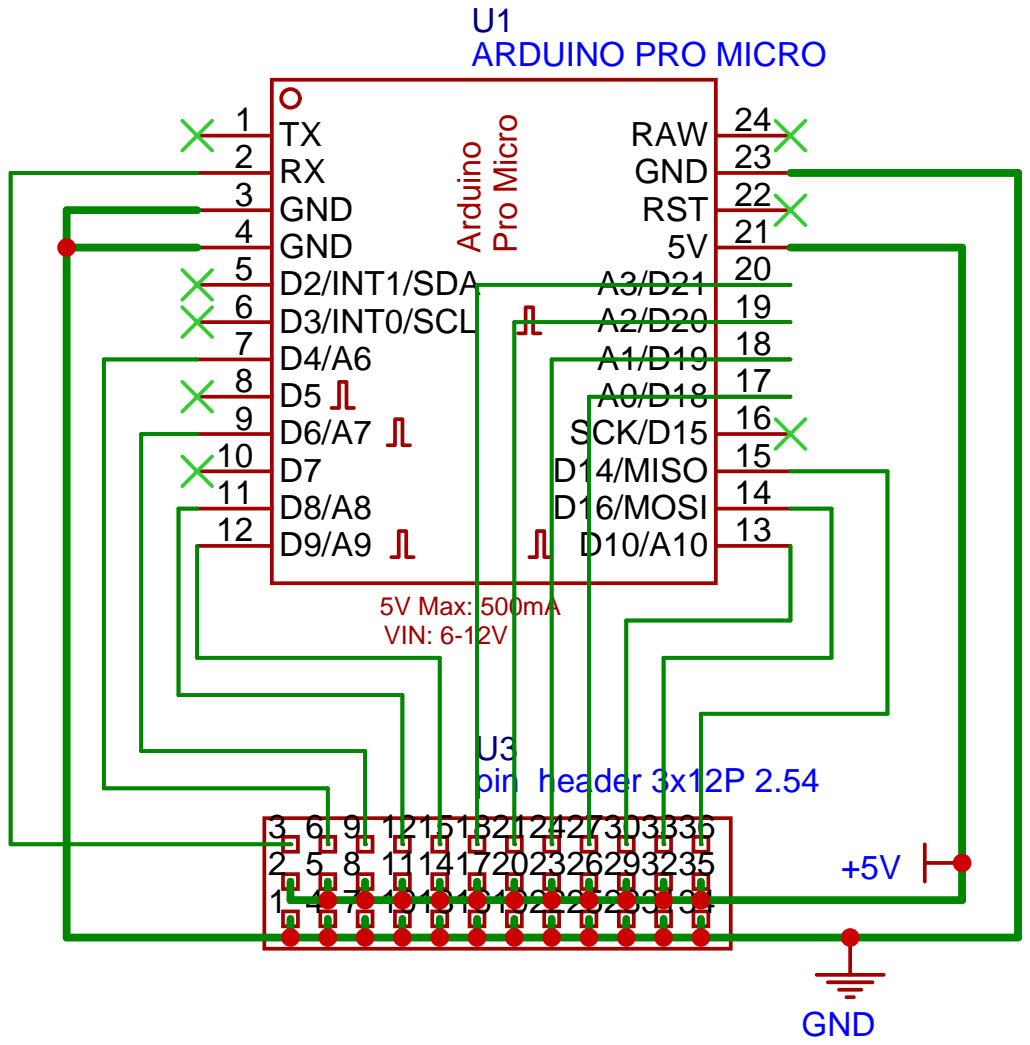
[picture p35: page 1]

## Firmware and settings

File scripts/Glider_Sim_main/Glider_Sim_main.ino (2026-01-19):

// Requires Arduino Joystick Library https://github.com/MHeironimus/ArduinoJoystickLibrary
#include <Joystick.h>

Joystick_ Joystick(JOYSTICK_DEFAULT_REPORT_ID,
                   JOYSTICK_TYPE_JOYSTICK);  //, 32, 1,
//true, true, true, false, false, false,
//true, false, false, true, false);
// false, false, false, false, false);

// RX no pino 14 (Aux 4), TX em -1 (desabilitado)

int bitResolution = 12;
long sampleValue = 0;
int numberOfSamples = 1;
int sampleMaxValue = 1 << bitResolution;

// Tolerância em duty-cycle para detetar níveis (±5%)
const float DUTY_TOL = 0.05;

// 6-buttons
// Níveis ideais (0, 1/6, 2/6, 3/6, 4/6, 5/6, 6/6)    (MAX_DUTY * dutyIndex) / STEPS;
  const int MAX_DUTY = 250;
  const int STEPS = 7;
const float dutyLevels[7] = {
  (MAX_DUTY * 1.0) / (STEPS * 255.0),        // 0 = nenhum botão
  (MAX_DUTY * 2.0) / (STEPS * 255.0),  // 1 = botão 1 (GPIO 0 no ESP32)
  (MAX_DUTY * 3.0) / (STEPS * 255.0),  // 2 = botão 2 (GPIO 1)
  (MAX_DUTY * 4.0) / (STEPS * 255.0),  // 3 = botão 3 (GPIO 6)
  (MAX_DUTY * 5.0) / (STEPS * 255.0),  // 4 = botão 4 (GPIO 20)
  (MAX_DUTY * 6.0) / (STEPS * 255.0),  // 5 = botão 5 (GPIO 10)
  (MAX_DUTY * 7.0) / (STEPS * 255.0)   // 6 = botão 6 (GPIO 5) → duty ≈ 100% (250)
};


const uint8_t LINEAR_PINS[] = {
  A6,  // JoystickX, Hall effect
  A7,  // JoystickY, Hall effect
  A8,  // Slider (Rudder?)
  A9,  // Slider (Air-break?)
  A3,  // Slider (Flaps?)
  A2,  // Slider (Trim?)
  A1,  // Slider (wheel up/down - D)
};

// buttons 0 to 5 (6 buttons) read from Serial port 1 - Stick
// buttons 6 and 7 read from Aux 1 and Aux 4 ports
int INIT_INT_PIN = 6;
// buttons 8 to 13 (6 buttons) read from Serial port Aux 2 - Menu 6-Buttons 1
int INIT_MB1_PIN = 8;
// buttons 14 to 19 (6 buttons) read from Serial port Aux 3 - Menu 6-Buttons 2
int INIT_MB2_PIN = 14;



const uint8_t SWITCH_PINS[] = {
  18,  // Aux 1 - switch
  14,  // Aux 4   switch
};


const uint8_t BUTTONS6_PINS[] = {
  10,  // Aux 2 - 6 botões
  16,  // Aux 3 - 6 botões
};

boolean lastSwitchState[sizeof(SWITCH_PINS)];


// estado atual dos dois keypads 6-botoes
int current6ButtonValue[sizeof(BUTTONS6_PINS)] = { 0 };
unsigned long lastPwmReadMillis = 0;
const unsigned long PWM_READ_INTERVAL = 20;  // ms entre leituras

void setup() {
  // Setup analog inputs
  for (size_t i = 0; i < sizeof(LINEAR_PINS); i++) {
    pinMode(LINEAR_PINS[i], INPUT_PULLUP);
  }
  // Setup digital switches
  for (size_t i = 0; i < sizeof(SWITCH_PINS); i++) {
    pinMode(SWITCH_PINS[i], INPUT_PULLUP);
  }

  // Setup PWM pins 6 button pins
  for (size_t i = 0; i < sizeof(BUTTONS6_PINS); i++) {
    pinMode(BUTTONS6_PINS[i], INPUT);
  }

  // Initialize Joystick Library
  Joystick.begin();
  Joystick.setXAxisRange(0, sampleMaxValue);
  Joystick.setYAxisRange(0, sampleMaxValue);
  Joystick.setZAxisRange(0, sampleMaxValue);
  Joystick.setRxAxisRange(0, sampleMaxValue);
  Joystick.setRyAxisRange(0, sampleMaxValue);
  Joystick.setRzAxisRange(0, sampleMaxValue);
  Joystick.setThrottleRange(0, sampleMaxValue);

  // Calculate number of samples
  numberOfSamples = (bitResolution - 10) < 1 ? 1 : 1 << ((bitResolution - 10) << 1);

  // Start comunication for debuging
  // Serial.begin(115200);
  // Start comunication with stick
  Serial1.begin(115200);
}

void loop() {

  // Read Switches from Serial - Stick
  while (Serial1.available() > 0) {
    char c = Serial1.read();

    if (c == '<') {
      uint8_t button = Serial1.parseInt();
      int state = Serial1.parseInt();

      if (button >= 20) {
        Joystick.setHatSwitch(button - 20, state);  // HAT switch
      } else if (button >= 0 && button <= 5) {      // Stick configurável até 6 botoes
        Joystick.setButton(button, state);
      }
    }
  }


  // Read Switches from board (Aux1 and Aux 4)
  for (size_t i = 0; i < sizeof(SWITCH_PINS); i++) {
    int currentButtonState = !digitalRead(SWITCH_PINS[i]);
    if (currentButtonState != lastSwitchState[i]) {
      Joystick.setButton(i + INIT_INT_PIN, currentButtonState);
      lastSwitchState[i] = currentButtonState;
    }
  }


  // Read Switches from 6-buttons keypad
  // Atualiza leitura dos keypads 6-botoes a cada PWM_READ_INTERVAL ms
  unsigned long now = millis();
  if (now - lastPwmReadMillis >= PWM_READ_INTERVAL) {
    lastPwmReadMillis = now;

    for (size_t i = 0; i < sizeof(BUTTONS6_PINS); i++) {
      int level = buttonPressed(BUTTONS6_PINS[i]);  // 0..6 ou -1

      if (level >= 0 && level != current6ButtonValue[i]) {
        current6ButtonValue[i] = level;

        // Exemplo de mapeamento: 6 níveis → 6 botões Joystick
        // Escolhe um offset adequado para este keypad
        int baseButtonIndex = (i == 0) ? INIT_MB1_PIN : INIT_MB2_PIN;

        // Primeiro limpa os 6 botões desse grupo
        for (int b = 0; b < 6; b++) {
          Joystick.setButton(baseButtonIndex + b, 0);
        }
        // set button active if pressed button is detected
        if (level > 0 && level <= 6) {
          Joystick.setButton(baseButtonIndex + (level - 1), 1);
        }
      }
    }
  }



  // Output Controls
  // Joystick.setXAxis(sampleMaxValue - overSample(LINEAR_PINS[0]));  // invert signal on X (otherwise change magnet polarity)
  Joystick.setXAxis(overSample(LINEAR_PINS[0]));
  Joystick.setYAxis(overSample(LINEAR_PINS[1]));
  Joystick.setZAxis(overSample(LINEAR_PINS[2]));
  Joystick.setRxAxis(overSample(LINEAR_PINS[3]));
  Joystick.setRyAxis(overSample(LINEAR_PINS[4]));
  Joystick.setRzAxis(overSample(LINEAR_PINS[5]));
  Joystick.setThrottle(overSample(LINEAR_PINS[6]));

  Joystick.sendState();
}

int overSample(int analogPin) {
  sampleValue = analogRead(analogPin);
  for (int n = 1; n < numberOfSamples; n++) {
    sampleValue += analogRead(analogPin);
  }
  return ((int)((sampleValue >> (bitResolution - 10)) + (1 << bitResolution - 11) - 1));
}





int buttonPressed(int PWM_IN_PIN) {
  const unsigned long TIMEOUT_US = 5000;  // 5 ms

  unsigned long highTime = pulseIn(PWM_IN_PIN, HIGH, TIMEOUT_US);
  unsigned long lowTime = pulseIn(PWM_IN_PIN, LOW, TIMEOUT_US);

  // Se não mediu ciclo completo, devolve -1 (sem alteração)
  if (highTime == 0 || lowTime == 0) {
    return -1;
  }

  unsigned long period = highTime + lowTime;
  float duty = (float)highTime / (float)period;

  int detectedLevel = -1;
  float bestDiff = 1.0;

  for (int i = 0; i < 7; i++) {
    float diff = fabs(duty - dutyLevels[i]);
    if (diff < bestDiff) {
      bestDiff = diff;
      detectedLevel = i;
    }
  }

  if (detectedLevel >= 0 && bestDiff <= DUTY_TOL) {
    return detectedLevel;  // 0..6
  } else {
    return -1;  // sem nível válido
  }
}

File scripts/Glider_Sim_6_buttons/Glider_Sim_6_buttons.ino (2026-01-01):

const int BTN_1_PIN = 0;   // 1/7
const int BTN_2_PIN = 1;   // 2/7
const int BTN_3_PIN = 6;   // 3/7
const int BTN_4_PIN = 20;  // 4/7
const int BTN_5_PIN = 10;  // 5/7
const int BTN_6_PIN = 5;   // 6/7

const int PWM_PIN   = 21;
const int LED_PIN   = 8;


void setup() {
  // Setup digital switches
  pinMode(BTN_1_PIN, INPUT_PULLUP);
  pinMode(BTN_2_PIN, INPUT_PULLUP);
  pinMode(BTN_3_PIN, INPUT_PULLUP);
  pinMode(BTN_4_PIN, INPUT_PULLUP);
  pinMode(BTN_5_PIN, INPUT_PULLUP);
  pinMode(BTN_6_PIN, INPUT_PULLUP);

  // Internal LED pin
  pinMode(LED_PIN, OUTPUT);

  pinMode(PWM_PIN, OUTPUT);
  analogWrite(PWM_PIN, 0);   // começa a 0% (nenhum botão)

  // Start comunication for debug
  // Serial.begin(115200);

}

void loop() {
  int dutyIndex = 1; // 1 = idle

if (digitalRead(BTN_1_PIN) == LOW)      dutyIndex = 2;
else if (digitalRead(BTN_2_PIN) == LOW) dutyIndex = 3;
else if (digitalRead(BTN_3_PIN) == LOW) dutyIndex = 4;
else if (digitalRead(BTN_4_PIN) == LOW) dutyIndex = 5;
else if (digitalRead(BTN_5_PIN) == LOW) dutyIndex = 6;
else if (digitalRead(BTN_6_PIN) == LOW) dutyIndex = 7;
// senão fica 1 (idle)

  // analogWrite no ESP32 aceita 0..255 por omissão (8 bits)
  const int MAX_DUTY = 250;
  const int STEPS = 7;
  int duty = (MAX_DUTY * dutyIndex) / STEPS;  // 1..7

  analogWrite(PWM_PIN, duty);

  // liga o led se um botão estiver pressionado
  if (dutyIndex > 1) {
    digitalWrite(LED_PIN, LOW);
  } else {
    digitalWrite(LED_PIN, HIGH);
  }

  // Serial.print("dutyIndex: ");
  // Serial.print(dutyIndex);
  // Serial.print("    duty: ");
  // Serial.println(duty);

  delay(100);
} 

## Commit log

2025-12-22 Added Joystick stl files
    Added all joystick stl files
    [Gummitasten_Mold_Unterseite.stl, Gummitasten_Mold_oberseite.stl, Joystick_Gimbal_Base.stl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]
2025-12-22 Add initial set of STL and PNG files for hardware parts
    Added new STL files for various hardware components including button boxes, chair holder, controller box, release mechanism, rudder, sliders, and trim. Also included PNG images for the release mechan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
    [6_Buttons_Box_Cover.stl, 6_Buttons_Box_main.stl, Chair_Holder.stl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]
2025-12-22 Update README with Bill of Materials and components
2025-12-22 Change 'Parafuso' to 'Screw' in README
    Updated terminology from 'Parafuso' to 'Screw' for clarity.
2025-12-22 Change 'Screw' to 'Bolt' in parts list
2025-12-23 Revise Bill of Materials with detailed component list
    Updated the Bill of Materials section with detailed information on aluminium profiles, joystick base components, joystick controller parts, and rudder pedals. Added links for purchasing components.
2025-12-23 Update credits section in README.md
    Added credit for joystick and rudder pedal designs.
2025-12-23 Add warning about BOM development status
    Added a warning about the BOM being under development and listed missing sections.
2025-12-23 Add Black Pigment item to Joystick Controller BOM
2025-12-26 Update BOM with sliders and chair holder sections
    Added detailed Bill of Materials tables for sliders (air-breaks, flaps, gear) and chair holder components. Updated and corrected formatting, descriptions, and links in existing BOM tables. Removed outdated warning about missing sections for sliders and chair holder.
2025-12-30 Normalize STL filenames and update documentation
    Renamed STL files and related assets to use lowercase, hyphen-separated naming for consistency and easier automation. Updated README to match new part names and added .github/copilot-instructions.md 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
    [6-buttons-box-cover.stl, 6-buttons-box-main.stl, buttons-support-no-pcb.stl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]
2025-12-30 Add STL filename validation workflow and script
    Introduces a GitHub Actions workflow that runs on push and pull requests to enforce lowercase, space-free naming for files and directories under the 'stl/' directory. Adds a Python script to perform 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
2025-12-30 Revert "Add STL filename validation workflow and script"
    This reverts commit 486e49e3325bdeb1d09a1c7f10574125d97bdcb2.
2026-01-01 Update and expand BOM in README.md
    Revised the Bill of Materials (BOM) to clarify bolt specifications (e.g., DIN912), update and correct product links, and break out sections for controller box, trim, release, 6-buttons box, and wiring/connectors. Quantities and descriptions were adjusted for accuracy, and a warning was updated to reflect new missing sections. This improves clarity and completeness for users sourcing parts.
2026-01-01 Add controller and button scripts for Glider Sim
    Added Arduino .ino source files for the main controller, 6-button controller, and stick buttons controller under the scripts directory. Updated README to remove missing code warnings for these components.
    [Glider_Sim_6_buttons.ino, Glider_Sim_controller.ino, Glider_Sim_stick_buttons.ino]
2026-01-02 Update component type in parts list
    Changed 'Crab Clamp' to 'Cables' for the 26AWG servo extension cable entry in the README parts list for accuracy.
2026-01-02 Add GliderSim 6 buttons PCB files and documentation
    Added Gerber files, schematic PDF, and board images for the GliderSim 6 buttons PCB. These files provide manufacturing data, visual references, and design documentation for the project.
2026-01-02 Add Glider_sim_6_buttons.obj 3D model file
    Introduces the Glider_sim_6_buttons.obj file, containing the 3D geometry and mesh data for the Glider_sim_6_buttons PCB design. This file is likely used for visualization or integration with CAD tool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
    [Glider_sim_6_buttons.obj]
2026-01-02 added second obj
    added second obj
    [3D_PCB1_2026-01-02.obj]
2026-01-02 Remove obsolete 3D model OBJ files
    Deleted 3D_PCB1_2026-01-02.obj and Glider_sim_6_buttons.obj from the PCBs/Glider_sim_6_buttons directory as they are no longer needed.
    [3D_PCB1_2026-01-02.obj, Glider_sim_6_buttons.obj]
2026-01-05 Add Glider Sim PCB files and update controller
    Added PCB design files, schematics, BOM, CPL, and images for Glider_sim_main and Glider_sim_stick. Updated Glider_Sim_controller.ino with new changes.
    [Glider_sim_stick_BOM.xlsx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]
2026-01-06 Update README: refine description and add useful notes
    - Removed 'assembly instructions' from project description
    - Removed 'under construction' note
    - Added NOTE about using GitHub Discussions for questions
    - Added TIP with Hall sensor installation video before Electronics section
2026-01-06 Update README with controller images and details
    Added images and descriptions for main controller, stick buttons controller, and 6-button box controller.
2026-01-06 Rename PCB ZIP files to GERBER naming convention
    Renamed ZIP files for Glider_sim_main and Glider_sim_stick_buttons to use the GERBER prefix for clarity and consistency in file naming.
2026-01-07 Add Introduction section before Bill of Materials
    Added detailed project introduction and assembly instructions.
2026-01-07 Enhance README with Table of Contents and clarifications
    Added a Table of Contents section for better navigation and clarified joystick button mapping in Condor 3 setup.
2026-01-08 Rename 'Condor 3 Setup' to 'Connections and Setup'
    Updated the README to rename 'Condor 3 Setup' section to 'Connections and Setup' and added detailed wiring instructions for joystick and auxiliary inputs.
2026-01-08 Improve comments and clarity in Glider_Sim_main.ino
    Updated comments for clarity and corrected phrasing in the Glider simulation code.
    [Glider_Sim_main.ino]
2026-01-19 Add photos of PCBs and stick button assemblies
    Added new images showing the front and back of PCBs, stick buttons, their assembly, options, and related STL files for documentation and reference.
2026-01-19 Update PCB files and add schematic image
    Updated GERBER, BOM, and CPL files for the Glider sim stick buttons PCB. Added a new schematic image to aid in hardware design and documentation.
    [Glider_sim_stick_BOM.xlsx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]
